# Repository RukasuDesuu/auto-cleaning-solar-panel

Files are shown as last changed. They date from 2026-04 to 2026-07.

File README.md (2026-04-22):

# ASCM - Sistema Automatizado de Limpeza e Arrefecimento de Painéis Fotovoltaicos




O **ASCM** (Automated Self-Cleaning and Cooling Mechanism) é um projeto de Engenharia de Controle e Automação focado em maximizar a eficiência de sistemas de energia solar fotovoltaica. O sistema combate os dois principais vilões da geração solar: o **soiling** (acúmulo de sujeira) e o **superaquecimento** das células.

## 🚀 Funcionalidades

- **Limpeza Automatizada:** Sistema de aspersão combinado com rodo motorizado (wiper) para remoção de poeira e crostas de sujeira (*hard scale*).
- **Arrefecimento Inteligente:** Monitoramento térmico em tempo real para acionar o resfriamento quando a temperatura ultrapassa os níveis ideais.
- **Sensoriamento em Tempo Real:** 
  - Comparação diferencial de potência entre o painel principal e um de referência.
  - Monitoramento de temperatura e condições ambientais.
- **Gestão Hídrica:** Projetado para uso otimizado de água, com foco em baixo custo e alta eficácia.

## 📊 Motivação Técnica

A eficiência de um painel solar é severamente afetada por fatores externos:
*   **Soiling:** O acúmulo de poeira pode reduzir a eficiência em até **7,84% por semana**. Em períodos de seca, as perdas podem ultrapassar **50%**.
*   **Temperatura:** Para cada grau Celsius acima de 25°C, a eficiência do módulo decresce entre **0,5% e 0,6%**.
*   **Aumento de Eficiência:** Estudos (Geetha et al., 2024) demonstram que o uso de ASCM pode elevar a eficiência de saída em até **14,81%**.

## 🛠️ Tecnologias e Componentes

Com base na arquitetura definida para o protótipo:

### Eletrônica e Controle
Para detalhes de montagem, pinagem e lista completa de componentes, consulte o [Guia de Hardware Eletrônico](hardware/Electronics/electronics.md).

- **Microcontrolador:** Arduino Uno.
- **Sensores:**
    - Corrente/Tensão: INA219.
    - Temperatura: Termopar Impermeável (feedback em malha fechada).
- **Atuadores:**
    - Motores: DC com Caixa de Redução.
    - Driver: Ponte H L298N.
    - Hidráulica: Mini-bomba 12V e bicos aspersores.

### Design e Software
- **Modelagem 3D:** Autodesk Inventor (design mecânico e simulação).
- **Firmware:** C++/Arduino (lógica de controle e sensoriamento).
- **Interface/Monitoramento:** Python (Dashboard para visualização de parâmetros).
- **Fabricação:** Impressão 3D (FDM) para peças estruturais e personalizadas.

## 📂 Estrutura do Repositório

```text
├── docs/            # Documentação, apresentações e artigo (LaTeX)
│   └── Presentations/main.* # [LEGADO] Conteúdo desatualizado
├── firmware/        # Código fonte do microcontrolador (C++/Arduino)
└── hardware/        # Design 3D (Inventor) e esquemas elétricos
    ├── CAD/         # Arquivos de modelagem 3D (.ipt, .iam)
    └── Electronics/  # Esquemáticos, listas de componentes e instruções de montagem
```

## 👥 Autores

*   **César Kerber**
*   **Lucas Ekroth**
*   **Paulo Rangel**

---
*Projeto desenvolvido como parte do Projeto Integrador do curso de Engenharia de Controle e Automação.*

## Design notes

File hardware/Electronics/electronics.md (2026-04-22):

# Hardware Eletrônico - Instruções de Montagem

Este documento descreve detalhadamente a parte eletrônica do projeto de Painel Solar Autolimpante (ASCM). O sistema utiliza a arquitetura **Telemetrix**, onde o microcontrolador (Arduino Uno) atua como um servidor de I/O e a lógica de controle é executada pelo backend em Python.

## 1. Lista de Componentes (BOM)

| Item | Quantidade | Descrição | Função no Projeto |
| :--- | :---: | :--- | :--- |
| **Microcontrolador** | 1 | Arduino Uno R3 | Interface de I/O (Firmware Telemetrix) |
| **Driver de Motor** | 1 | Ponte H L298N | Controle do motor de movimentação (Wiper) |
| **Motor DC** | 1 | Motor 5V com Redução | Movimentação da escova/rodo |
| **Bomba d'água** | 1 | Mini-bomba Submersível 5V | Sistema de aspersão e arrefecimento |
| **Sensores de Potência** | 2 | Módulo INA219 (I2C) | Monitoramento de V/I do painel principal e ref. |
| **Sensores Fim de Curso** | 2 | Micro-switch (Chave NF/NA) | Limitação física do movimento do rodo |
| **Sensor de Temperatura** | 1 | Termopar Impermeável / LM35 | Monitoramento térmico da superfície |
| **Sensor de Luz** | 1 | LDR (Resistor Dependente de Luz) | Medição de irradiância/luminosidade |
| **Resistor de Carga** | 2 | 33 $\Omega$ (Potência >= 1.5W) | Carga para medição de potência dos painéis |
| **Resistor LDR** | 1 | 10 k$\Omega$ (0.25W) | Resistor para divisor de tensão do LDR |
| **Painel Solar** | 2 | Painéis Fotovoltaicos | Geração de energia e referência de sujeira |

## 2. Diagrama de Pinagem (Pinout) - Arduino Uno

Abaixo estão as conexões reais configuradas no sistema:

| Componente | Pino Arduino | Tipo | Descrição |
| :--- | :---: | :---: | :--- |
| **Ponte H (ENA)** | 11 | PWM | Velocidade do motor (Wiper) |
| **Ponte H (IN1)** | 9 | Digital | Direção do motor (Wiper) |
| **Ponte H (IN2)** | 10 | Digital | Direção do motor (Wiper) |
| **Ponte H (ENB)** | 6 | PWM | Velocidade/Fluxo da bomba |
| **Ponte H (IN3)** | 7 | Digital | Ativação da bomba |
| **Ponte H (IN4)** | 8 | Digital | Ativação da bomba |
| **Fim de Curso (Home)** | 2 | Digital | Sensor de posição inicial |
| **Fim de Curso (End)** | 3 | Digital | Sensor de posição final |
| **Sensor de Luz (LDR)** | A0 | Analógico | Leitura de luminosidade |
| **Temp. Superfície** | A1 | Analógico | Leitura de temperatura |
| **INA219 #1 (Principal)** | A4/A5 | I2C (0x40) | Monitoramento do Painel com limpeza |
| **INA219 #2 (Ref.)** | A4/A5 | I2C (0x41) | Monitoramento do Painel de Referência |

## 3. Esquemático Visual (Fritzing)

Para facilitar a montagem, utilize o diagrama visual abaixo:

> 📥 **[Baixar Esquemático em PDF (Alta Resolução)](diagram.pdf)**

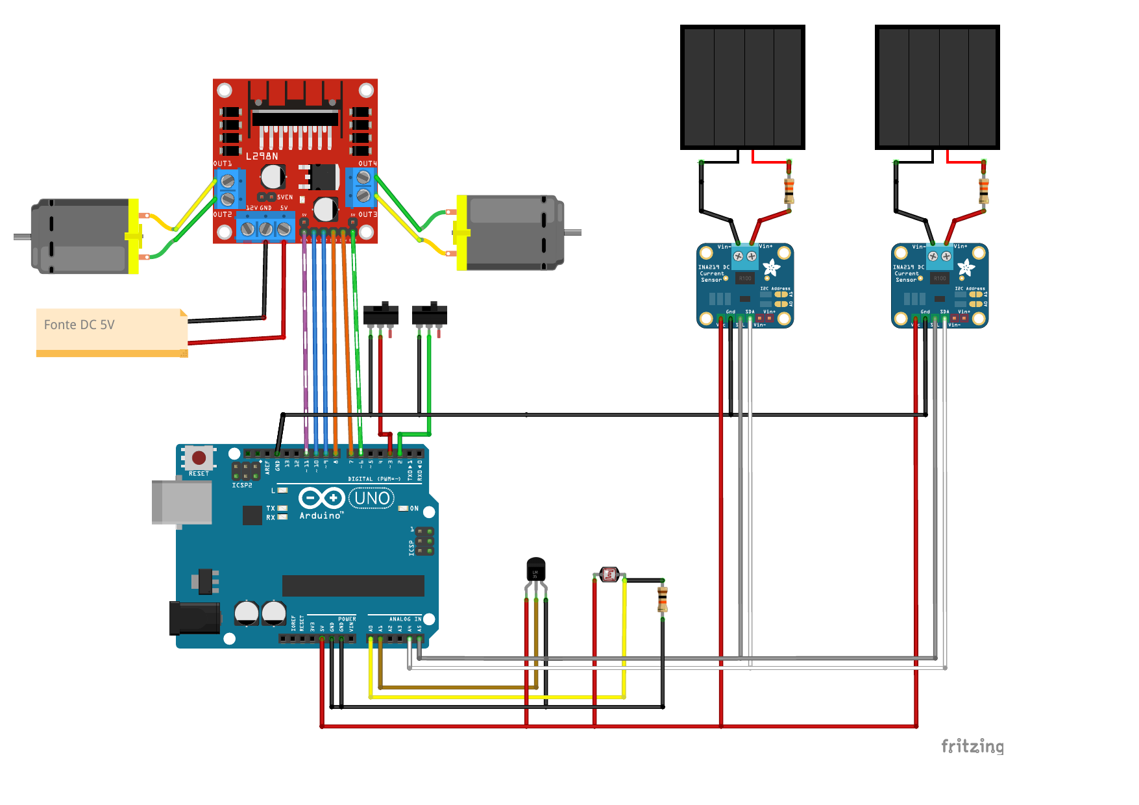
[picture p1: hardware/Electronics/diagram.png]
Diagrama de Montagem Fritzing

*Nota: Caso a imagem acima não carregue, exporte o seu projeto no Fritzing como PNG e salve-o com o nome `diagram.png` nesta pasta.*

## 4. Configuração do Barramento I2C (Sensores de Potência)
Como utilizamos dois sensores INA219 no mesmo par de fios (A4 e A5), é obrigatório que eles tenham endereços diferentes.
*   **INA219 Principal:** Mantenha a configuração original (Endereço `0x40`).
*   **INA219 Referência:** Você deve realizar uma pequena ponte de solda no pad identificado como **A0** na placa do módulo (isso mudará o endereço para `0x41`).

## 5. Arquitetura de Controle
O projeto não utiliza um arquivo `.ino` customizado. Para que o sistema funcione:
1. Carregue o firmware **Telemetrix4Arduino** no seu Arduino Uno via Arduino IDE.
2. O backend Python (`hardware.py`) gerencia a leitura dos dois endereços I2C simultaneamente.

## 6. Instruções de Montagem

### Passo 1: Alimentação Externa
Os motores e a bomba consomem mais corrente do que o Arduino pode fornecer. Use uma fonte externa de **5V** conectada à Ponte H. **Lembre-se de unir o GND da fonte externa com o GND do Arduino.**

### Passo 2: Sensores Fim de Curso
Instale as chaves de fim de curso nas extremidades do trilho do rodo. Elas estão configuradas como `INPUT_PULLUP`, portanto, devem conectar o pino ao **GND** quando acionadas.

### Passo 3: Divisor de Tensão (LDR)
O LDR deve ser montado em série com o resistor de **10k $\Omega$**. Conecte o ponto central (divisor) ao pino **A0** do Arduino para garantir leituras precisas de luminosidade.

### Passo 4: Resistores de Carga e INA219
Os resistores de **33 $\Omega$ / 1.5W** devem ser conectados como carga dos painéis solares. O INA219 deve ser intercalado entre o painel e este resistor para medir a corrente e a tensão real gerada. 
> **Atenção:** Estes resistores podem aquecer durante a operação. Certifique-se de que não estejam em contato com partes plásticas sensíveis.

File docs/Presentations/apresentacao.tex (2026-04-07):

\documentclass[aspectratio=169, xcolor={table}]{beamer}

\usepackage[utf8]{inputenc}
\usepackage[T1]{fontenc}
\usepackage[brazil]{babel}
\usepackage{graphicx}
\usepackage{amsmath}
\usepackage{booktabs}

% Configuração do Tema
\usetheme{Madrid}
\usecolortheme{whale}

% Informações do Título
\title[ASCM - Limpeza e Arrefecimento]{Sistema Automatizado de Limpeza e Arrefecimento de Painéis Fotovoltaicos (ASCM)}
\subtitle{Proposta de Projeto Integrado - Engenharia de Controle e Automação}
\author[César, Lucas, Paulo]{
    Equipe: \\
    César Kerber, Lucas Ekroth, Paulo Rangel
}
\institute[IFSP]{
    \textbf{Orientador:} Prof. Valdeci Donizete Gonçalves \\
}
\date{\today}

\begin{document}

% Slide de Título
\begin{frame}
    \titlepage
\end{frame}

% --- Introdução e Motivação ---
\section{Introdução e Motivação}

\begin{frame}{Contexto Global: Transição Energética}
    \begin{columns}
        \column{0.5\textwidth}
        \begin{itemize}
            \item \textbf{Crescimento Exponencial:} Solar e Eólica já representam 1/3 da geração no Brasil (Ember, 2024).
            \item \textbf{União Europeia:} Fontes renováveis atingiram 30\% da matriz em 2026.
            \item \textbf{Desafio Crítico:} Manter a eficiência máxima operacional desses ativos.
        \end{itemize}
        \begin{center}
            \textit{O aumento da capacidade exige soluções de manutenção autônomas.}
        \end{center}
        \column{0.5\textwidth}
        \begin{figure}
            \centering
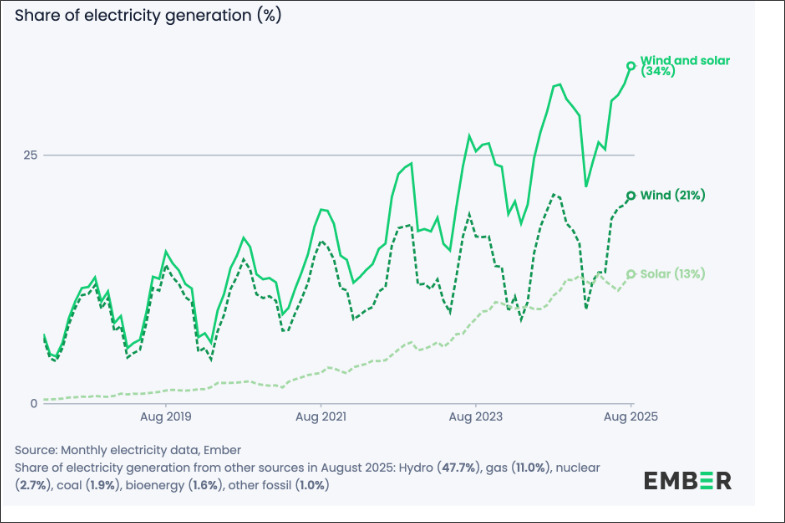
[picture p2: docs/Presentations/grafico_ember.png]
            
            \caption{\footnotesize Geração Elétrica Renovável no Brasil (Ember, 2024).}
        \end{figure}
    \end{columns}
\end{frame}

\section{Problemática}

\begin{frame}{O Problema: Acúmulo de Poeira (\textit{Soiling})}
    \begin{columns}
        \column{0.5\textwidth}
        \begin{itemize}
            \item \textbf{Perdas de Eficiência:} Redução de até \textbf{7,84\% por semana} (Qi et al., 2025).
            \item \textbf{Cenários Críticos:} Perdas superiores a \textbf{50\%} em períodos de seca prolongada.
            \item \textbf{Efeito Físico:} Sombreamento das células e obstrução da radiação solar direta.
        \end{itemize}
        \column{0.5\textwidth}
        \begin{figure}
            \centering
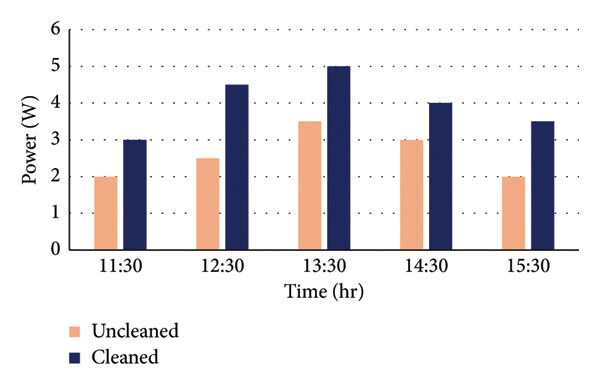
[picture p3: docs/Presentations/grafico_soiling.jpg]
            
            \caption{\footnotesize Estudo sobre o impacto do \textit{soiling}. GEETHA, A. et al. (2025)}
        \end{figure}
    \end{columns}
\end{frame}

\begin{frame}{O Problema: Impacto Térmico}
    \begin{columns}
        \column{1\textwidth}
        \begin{itemize}
            \item \textbf{Coeficiente de Temperatura:} Decréscimo de \textbf{0,5\% a 0,6\%} por $^\circ$C acima de 25$^\circ$C.
            \item \textbf{Efeito Cumulativo:} Poeira retém calor na superfície.
            \item \textbf{Necessidade:} Sistema integrado de limpeza + \textit{cooling}.
        \end{itemize}
    \end{columns}
\end{frame}

\section{Estado da Arte}

\begin{frame}{Revisão Bibliográfica: Métodos de Limpeza}
    \begin{table}[]
        \centering
        \footnotesize
        \begin{tabular}{@{}lll@{}}
        \toprule
        \textbf{Método} & \textbf{Vantagens} & \textbf{Desvantagens} \\ \midrule
        \textbf{Robótica Autônoma} & Alta eficácia, sem água & Custo elevado, manutenção complexa \\
        \textbf{Revestimentos Nano} & Passivo, repele água & Custo proibitivo, baixa durabilidade \\
        \textbf{Aspersão + Wiper (ASCM)} & \textbf{Baixo custo, alta eficácia} & Consumo de água (se não gerido) \\ \bottomrule
        \end{tabular}
    \end{table}
    \begin{block}{Justificativa Técnica}
        Estudos de Geetha et al. (2024) demonstraram um aumento de \textbf{14,81\%} na eficiência utilizando o método de aspersão com rodo mecânico.
    \end{block}
\end{frame}

\begin{frame}{O Fenômeno de \textit{Dust Scaling}}
    \begin{itemize}
        \item \textbf{Formação de "Crosta":} A umidade (orvalho) cristaliza minerais solúveis entre as partículas de poeira e o vidro.
        \item \textbf{Adesão:} Cria-se uma camada rígida (\textit{hard scale}) difícil de remover apenas com ar.
        \item \textbf{Solução Integrada:} Uso otimizado de água para dissolver a crosta e ação mecânica para a remoção completa.
    \end{itemize}
\end{frame}

% --- Corpo do Projeto ---

\section{Objetivo Geral}
\begin{frame}{Objetivo Geral}
    \begin{block}{O que se espera do protótipo?}
        Desenvolver um protótipo de sistema automatizado de \textbf{baixo custo} para:
        \begin{itemize}
            \item \textbf{Limpeza Mecânica:} Remoção de poeira e detritos (\textit{soiling}).
            \item \textbf{Arrefecimento Térmico:} Controle de temperatura da superfície.
            \item \textbf{Sensoriamento em Tempo Real:} Monitoramento de potência e condições ambientais.
            \item \textbf{Gestão Hídrica:} Uso racional de água com potencial de reaproveitamento.
        \end{itemize}
    \end{block}
\end{frame}

\section{Materiais}
\begin{frame}{Materiais - Detalhamento de Componentes}
    \begin{columns}
        \column{0.5\textwidth}
        \textbf{Eletrônica e Controle:}
        \begin{itemize}
            \item Microcontrolador: Arduino Uno.
            \item Sensores de Corrente: INA219.
            \item Sensor de Temperatura: Termopar Impermeável.
            \item Driver de Motor: Ponte H L298N.
            \item Resistor de Carga (Potência).
        \end{itemize}

        \column{0.5\textwidth}
        \textbf{Mecânica e Estrutura:}
        \begin{itemize}
            \item Motores: DC com Redução.
            \item Atuadores Hídricos: Mini-bomba 12V e bicos aspersores.
            \item Estrutura: Peças em Impressão 3D.
        \end{itemize}
    \end{columns}
\end{frame}

\section{Metodologia}
\subsection{Hardware}
\begin{frame}{Metodologia - Hardware}
    \begin{itemize}
        \item \textbf{Arquitetura:} Integração de sensores para feedback em malha fechada.
        \item \textbf{Acionamento:} Sistema de movimentação linear para o rodo (\textit{wiper}).
    \end{itemize}
\end{frame}

\subsection{Software}
\begin{frame}{Metodologia - Software (Design 3D e Firmware)}
    \begin{itemize}
        \item \textbf{Modelagem 3D:} Utilização do software \textbf{Inventor} para design mecânico e simulação de movimentos.
        \item \textbf{Desenvolvimento de Firmware:} Linguagem C++/Arduino para lógica de controle.
        \item \textbf{Dashboard:} Interface simples para monitoramento e configuração de parâmetros via \textbf{Python}.
    \end{itemize}
\end{frame}

\subsection{Ferramentas de Execução}
\begin{frame}{Metodologia - Ferramentas de Execução}
    \begin{itemize}
        \item \textbf{Prototipagem Rápida:} Impressão 3D (FDM) para peças personalizadas.
        \item \textbf{Ambiente de Programação:} VS Code + Arduino IDE.
        \item \textbf{Instrumentação:} Multímetro e protoboards para validação de circuitos.
    \end{itemize}
\end{frame}

\section{Cronograma}

\begin{frame}{Cronograma Detalhado (Parte 1: Março e Abril)}
    \centering
    \scriptsize
    \begin{tabular}{|l|c|c|c|c|c|c|c|c|c|}
    \hline
    \textbf{Atividade / Semana} & \textbf{S1} & \textbf{S2} & \textbf{S3} & \textbf{S4} & \textbf{S5} & \textbf{S6} & \textbf{S7} & \textbf{S8} & \textbf{S9} \\ \hline
    \textit{Datas (Início da Sem.)} & \tiny 03/03 & \tiny 10/03 & \tiny 17/03 & \tiny 24/03 & \tiny 31/03 & \tiny 07/04 & \tiny 14/04 & \tiny 21/04 & \tiny 28/04 \\ \hline
    Revisão Bibliográfica & X & X & X & & & & & & \\ \hline
    Definição/Compra Materiais & & X & X & X & X & X & & & \\ \hline
    \textbf{Design 3D (Inventor)} & & & & & \cellcolor{blue!20}X & \cellcolor{blue!20}X & \cellcolor{blue!20}X & & \\ \hline
    \textbf{Programação (Firmware)} & & & & & \cellcolor{blue!20}X & \cellcolor{blue!20}X & \cellcolor{blue!20}X & \cellcolor{blue!20}X & \cellcolor{blue!20}X \\ \hline
    Escrita do Artigo & & & & & & & \cellcolor{yellow!20}X & \cellcolor{yellow!20}X & \cellcolor{yellow!20}X \\ \hline
    \end{tabular}
\end{frame}

\begin{frame}{Cronograma Detalhado (Parte 2: Maio a Junho)}
    \centering
    \scriptsize
    \begin{tabular}{|l|c|c|c|c|c|c|c|c|}
    \hline
    \textbf{Atividade / Semana} & \textbf{S10} & \textbf{S11} & \textbf{S12} & \textbf{S13} & \textbf{S14} & \textbf{S15} & \textbf{S16} & \textbf{S17} \\ \hline
    \textit{Datas (Início da Sem.)} & \tiny 05/05 & \tiny 12/05 & \tiny 19/05 & \tiny 26/05 & \tiny 02/06 & \tiny 09/06 & \tiny 16/06 & \tiny 23/06 \\ \hline
    Montagem Mecânica/Eletrônica & X & X & X & & & & & \\ \hline
    Refino de Software & X & X & X & X & & & & \\ \hline
    Testes e Validação & & & & X & X & X & X & \\ \hline
    Finalização do Artigo & & & & & X & X & X & \cellcolor{red!20}\textbf{FIM} \\ \hline
    \end{tabular}
\end{frame}

\section{Bibliografia}
\begin{frame}{Bibliografia Selecionada}
    \footnotesize
    \begin{itemize}
        \item \textbf{GEETHA, A. et al.} Solar Panel Self-Cleaning Mechanisms and Its Effect on the Economic and Environmental Sustainability. Journal of Electrical and Computer Engineering, 2024.
        \item \textbf{QI, J. et al.} Combining dust scaling behaviors of PV panels and water cleaning methods. Renewable and Sustainable Energy Reviews, 2025.
        \item \textbf{CAVALCANTE, M. M. et al.} Protótipo de um sistema automatizado para higienização de painéis solares... Anais do V SINGEP, 2016.
        \item \textbf{EMBER.} European Electricity Review 2026 \& Brazil Wind/Solar Report 2024.
    \end{itemize}
\end{frame}

\end{document}

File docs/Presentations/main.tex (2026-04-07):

\documentclass[12pt, a4paper]{article}

\usepackage[utf8]{inputenc}
\usepackage[T1]{fontenc}
\usepackage[brazil]{babel}
\usepackage{geometry}
\geometry{a4paper, margin=2.5cm}
\usepackage{graphicx}
\usepackage{amsmath}
\usepackage{hyperref}
\usepackage{titlesec}
\usepackage{booktabs}
\usepackage{xcolor}

\hypersetup{
    colorlinks=true,
    linkcolor=blue,
    filecolor=magenta,
    urlcolor=cyan,
    citecolor=black,
}

\titleformat{\section}{\large\bfseries\color{blue!60!black}}{\thesection}{1em}{}
\titleformat{\subsection}{\normalsize\bfseries\color{blue!50!black}}{\thesubsection}{1em}{}

\title{
    \vspace{-1cm}
    \Large \textbf{Engenharia de Controle e Automação} \\
    \vspace{1cm}
    \Huge \textbf{Proposta de Projeto Integrado} \\
    \vspace{0.5cm}
    \LARGE \textcolor{blue!60!black}{Sistema Automatizado de Limpeza e Arrefecimento de Painéis Fotovoltaicos (ASCM)}
}
\author{\textbf{} César Kerber\\ Lucas Ekroth\\ Paulo Rangel}
\date{\today}

\begin{document}

\maketitle

\thispagestyle{empty}

\vspace{1.5cm}

\begin{abstract}
\noindent A eficiência de sistemas solares fotovoltaicos é frequentemente comprometida pelo acúmulo de poeira e aumento da temperatura nas células. Esta proposta apresenta o projeto de um sistema automatizado para a limpeza e arrefecimento de painéis fotovoltaicos, embasado no estado da arte atual. O sistema visa monitorar as condições do painel e do ambiente para realizar a limpeza e o resfriamento de forma autônoma, visando maximizar a geração de energia e prolongar a vida útil dos módulos, com foco em baixo custo e viabilidade econômica.
\end{abstract}

\newpage
\tableofcontents
\newpage

\section{Introdução e Problematização}

A motivação para o desenvolvimento deste sistema fundamenta-se no crescimento exponencial da energia solar fotovoltaica como pilar da transição energética global. De acordo com relatórios da \textit{Ember} \cite{ember_brazil_2024, ember_eu_2026}, o avanço das fontes renováveis é notável: no Brasil, a combinação das energias solar e eólica já responde por aproximadamente um terço da geração elétrica nacional \cite{ember_brazil_2024}. Na União Europeia, essas fontes já atingiram a marca de 30\% da matriz \cite{ember_eu_2026}, refletindo uma tendência mundial de expansão da capacidade instalada e a necessidade crítica de manter esses ativos operando em sua eficiência máxima.

A energia solar fotovoltaica tem se destacado como uma das principais fontes de energia renovável. No entanto, a eficiência dos sistemas fotovoltaicos (PV) é severamente comprometida pelo fenômeno do \textit{soiling} (acúmulo de poeira, detritos e poluentes). Conforme reportado por Qi et al. (2025) \cite{qi2025}, o acúmulo de poeira pode reduzir a eficiência em até \textbf{7,84\% por semana} em determinadas regiões, podendo chegar a perdas totais superiores a \textbf{50\%} em períodos de seca prolongada.

Além do sombreamento físico, que impede a radiação solar de atingir a célula, o acúmulo de sujeira contribui para o aumento da temperatura de operação das células. Geetha et al. (2024) \cite{geetha2024} destacam que para cada grau Celsius acima da temperatura ideal (geralmente 25$^\circ$C), a eficiência do módulo decresce entre \textbf{0,5\% e 0,6\%}. Portanto, um sistema eficaz não deve apenas focar na remoção de sujidades, mas também auxiliar na regulação térmica dos painéis solares para garantir a máxima eficiência.

\section{Estado da Arte e Revisão Bibliográfica}

\subsection{Mecanismos de Limpeza}
A literatura atual classifica os métodos de limpeza em ativos e passivos. O estado da arte aponta para:
\begin{itemize}
    \item \textbf{Sistemas de Aspersão e Rodo (Wiper):} Utilizam bicos nebulizadores combinados com braços mecânicos acionados por motores. O estudo empírico de Geetha et al. (2024) \cite{geetha2024} demonstrou um aumento de \textbf{14,81\%} na eficiência de saída utilizando este método em um sistema \textit{Automatic Self-Cleaning Mechanism (ASCM)} controlado por Arduino, provando ser uma solução de baixo custo e alta eficácia.
    \item \textbf{Limpeza Robótica:} Robôs autônomos que percorrem as fileiras de painéis utilizando escovas rotativas. Embora eficazes e capazes de atuar sem água em alguns casos, apresentam alto custo de implementação, manutenção complexa e desafios de navegação entre módulos (Qi et al., 2025) \cite{qi2025}.
    \item \textbf{Revestimentos Super-hidrofóbicos:} Métodos passivos que utilizam nanotecnologia, como filmes nano-revestidos (ex: dióxido de titânio), para repelir água e poeira, reduzindo a adesão das partículas via forças de Van der Waals (Qi et al., 2025) \cite{qi2025}. Apesar de inovadores, ainda possuem custo elevado e durabilidade limitada sob condições severas.
\end{itemize}

\subsection{Fenômeno de \textit{Dust Scaling}}
Pesquisas recentes (Qi et al., 2025) \cite{qi2025} revelam que a umidade relativa (entre 40\% e 80\%) facilita a formação de "pontes líquidas" de capilaridade entre as partículas de poeira e a superfície do vidro. Após a evaporação (como o orvalho matinal), minerais solúveis cristalizam-se formando uma crosta rígida e aderente (\textit{hard scale}). Isso justifica fortemente a necessidade de uma limpeza não apenas mecânica, mas com uso otimizado de água para dissolver essa camada, e reforça a importância de limpezas frequentes antes que a poeira se consolide na superfície do painel.

\subsection{Gestão Hídrica e Sustentabilidade}
A viabilidade ambiental do projeto em larga escala depende do uso racional da água. Cavalcante et al. (2016) \cite{cavalcante2016} propuseram em seu protótipo sistemas de \textbf{reaproveitamento da água da chuva} e da própria água de limpeza, utilizando filtros físicos para retenção de particulados graúdos e finos antes do retorno ao reservatório principal. Este conceito é fundamental para reduzir o custo operacional e o impacto ambiental do sistema automático.

\section{Objetivos}

\subsection{Objetivo Geral}
Desenvolver um protótipo de sistema automatizado de baixo custo para limpeza e arrefecimento térmico de painéis solares, integrando sensoriamento inteligente em tempo real e conceitos de gestão hídrica sustentável.

\subsection{Objetivos Específicos}
\begin{itemize}
    \item Implementar lógica de controle baseada na \textbf{comparação diferencial de potência} (corrente/tensão) entre um Painel de Referência (mantido limpo) e o Painel Principal.
    \item Integrar sensores de temperatura da superfície do painel, sensor de chuva e sensor de umidade para otimizar os gatilhos dos ciclos de limpeza e acionar o arrefecimento (\textit{cooling}) de forma inteligente.
    \item Desenvolver e modelar um mecanismo eletromecânico de varredura (rodo motorizado) impulsionado por motores DC ou de passo.
    \item Projetar um sistema de aspersão de água que minimize o desperdício, dimensionando bomba e bicos de forma eficiente.
\end{itemize}

\section{Metodologia Proposta}

\subsection{Arquitetura e Hardware do Sistema}
O controle do sistema será centralizado em um microcontrolador da família \textbf{ESP32} ou \textbf{Arduino Uno}, escolhidos pelo balanço entre custo, bibliotecas disponíveis e capacidade de integração.
\begin{itemize}
    \item \textbf{Sensoriamento:} Módulos de sensor de corrente (ex: INA219 ou ACS712) para monitorar a performance elétrica em tempo real. Um sensor de temperatura (ex: termopar impermeável DS18B20) para acionar o arrefecimento, e um sensor de chuva para impedir limpezas desnecessárias.
    \item \textbf{Atuadores:} Motores com caixa de redução (\textit{Geared DC Motors}) acionados por pontes H (ex: L298N) ou Motores de Passo (NEMA 17) para movimento linear suave do rodo sobre trilhos de alumínio. Uma mini-bomba d'água DC de 12V será responsável pelo envio de água ao sistema de aspersão.
\end{itemize}

\subsection{Estratégia de Controle}
A estratégia de acionamento seguirá os seguintes limiares:
\begin{enumerate}
    \item \textbf{Gatilho por Sujeira:} Se a diferença de potência medida $\Delta P = (P_{referencia} - P_{atual})$ for maior que o limite configurado (ex: queda de 10-15\% na corrente esperada), o ciclo de aspersão e raspagem mecânica é iniciado.
    \item \textbf{Gatilho por Temperatura:} Se a temperatura do painel $T_{painel} > 45^\circ\text{C}$ (ajustável), o sistema aciona brevemente a bomba para criar uma lâmina de água sobre o módulo, induzindo resfriamento evaporativo.
\end{enumerate}

\subsection{Custos Estimados e Desenvolvimento Físico}
Baseado nos modelos da literatura, a montagem do protótipo focará em itens comerciais de prateleira (COTS). O custo estimado para o desenvolvimento do protótipo funcional em escala reduzida está na faixa de \textbf{R\$ 450,00 a R\$ 800,00}, utilizando estruturas como perfis de alumínio e peças em impressão 3D.

\section{Resultados Esperados}
\begin{itemize}
    \item \textbf{Ganho de Eficiência Elétrica:} Recuperação e manutenção de cerca de \textbf{15\% a 20\%} da energia que seria perdida devido ao acúmulo de poeira.
    \item \textbf{Mitigação Térmica:} Redução da temperatura de operação em até \textbf{5$^\circ$C a 10$^\circ$C} durante picos de calor irradiante.
    \item \textbf{Viabilidade:} Demonstração prática de que o custo da automação implantada se paga rapidamente devido à energia excedente gerada ao longo do ano.
\end{itemize}

\vspace{1cm}

\begin{thebibliography}{99}

\bibitem{ember_eu_2026}
EMBER.
\textit{European Electricity Review 2026}.
Disponível em: \url{https://ember-energy.org/latest-insights/european-electricity-review-2026/}. Acesso em: 24 mar. 2026.

\bibitem{ember_brazil_2024}
EMBER.
\textit{Wind and solar generate over a third of Brazil's electricity for the first month on record}.
Disponível em: \url{https://ember-energy.org/latest-insights/wind-and-solar-generate-over-a-third-of-brazils-electricity-for-the-first-month-on-record/}. Acesso em: 24 mar. 2026.

\bibitem{geetha2024}
GEETHA, A.; USHA, S.; SANTHAKUMAR, J.; PALANISAMY, R.; SARAWAGI, R.; SINGH, A. 
\textit{Solar Panel Self-Cleaning Mechanisms and Its Effect on the Economic and Environmental Sustainability}. 
\textbf{Journal of Electrical and Computer Engineering}, Hindawi, vol. 2024, Article ID 7726716, 2024.

\bibitem{qi2025}
QI, Jiacheng; DONG, Qichang; SONG, Ye; ZHAO, Xiaoqing; SHI, Long.
\textit{Combining dust scaling behaviors of PV panels and water cleaning methods}. 
\textbf{Renewable and Sustainable Energy Reviews}, Elsevier, vol. 212, 115394, 2025.

\bibitem{cavalcante2016}
CAVALCANTE, M. M.; MARCELINO, J. E. C.; DELGADO, D. B. M.; VIANA, E. C.
\textit{Protótipo de um sistema automatizado para higienização de painéis solares planos agrupado a um sistema de reaproveitamento de água}. 
In: \textbf{Anais do V SINGEP}, São Paulo – SP, Brasil, 2016.

\end{thebibliography}

\end{document}

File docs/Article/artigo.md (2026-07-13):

# Desenvolvimento de Sistema Automatizado para Limpeza e Arrefecimento de Painéis Fotovoltaicos (ASCM)

**Autores:**
*   César Kerber
*   Lucas Ekroth
*   Paulo Rangel

*Curso de Engenharia de Controle e Automação*  
*Instituto Federal de Educação, Ciência e Tecnologia de São Paulo (IFSP)*  
*Orientador: Prof. Valdeci Donizete Gonçalves*

---

## Resumo

A eficiência de sistemas solares fotovoltaicos é severamente afetada por fatores ambientais externos, sendo o acúmulo de sujeira (*soiling*) e o superaquecimento das células os dois principais fatores de perda de geração. Este trabalho apresenta o desenvolvimento de um protótipo de Sistema Automatizado de Limpeza e Arrefecimento de Painéis Fotovoltaicos (*Automated Self-Cleaning and Cooling Mechanism* - ASCM). O sistema realiza a limpeza mecânica por meio de aspersão de água combinada com um rodo motorizado, e o resfriamento evaporativo por meio do acionamento de uma mini-bomba hidráulica. 

A lógica de controle é baseada em microcontrolador Arduino Uno rodando o protocolo Telemetrix, integrado a um backend Python (FastAPI) e a um dashboard em Streamlit para monitoramento em tempo real. O acionamento da limpeza é guiado de forma inteligente pela comparação diferencial de potência entre um painel principal e um painel de referência mantido limpo. Este artigo descreve a arquitetura eletromecânica, o desenvolvimento de software e estabelece a metodologia para os ensaios práticos de diminuição de eficiência e validação térmica a serem conduzidos com o protótipo completo.

**Palavras-chave:** Energia Solar Fotovoltaica. Soiling. Arrefecimento Térmico. Automação. Arduino.

---

## 1. Introdução

A transição energética global em direção a fontes renováveis tem posicionado a energia solar fotovoltaica como um dos pilares fundamentais da matriz elétrica de diversos países. Segundo relatórios da organização de estudos energéticos *Ember* (2024, 2026), o Brasil alcançou a marca histórica em que a geração eólica e solar fotovoltaica combinadas ultrapassam um terço da eletricidade produzida no país, conforme ilustrado no gráfico da Figura 1. Paralelamente, na União Europeia, as fontes renováveis atingiram cerca de 30% da matriz elétrica. Com o crescimento exponencial da capacidade instalada, torna-se crítico assegurar que esses ativos operem com o máximo aproveitamento energético possível.

Geração Renovável no Brasil
*Figura 1: Geração elétrica renovável no Brasil, evidenciando o crescimento de eólica e solar. Fonte: Adaptado de Ember (2024).*

Apesar dos avanços tecnológicos nos materiais semicondutores, a eficiência operacional de um módulo fotovoltaico é drasticamente degradada por variáveis externas em campo. O primeiro fator crítico é o acúmulo de poeira, pólen, dejetos e poluentes suspensos no ar na superfície de vidro do painel, fenômeno conhecido na literatura como *soiling* (Qi et al., 2025). A poeira depositada obstrui a radiação solar direta que penetra nas junções p-n, diminuindo a corrente gerada. Estudos apontam que o acúmulo contínuo de poeira pode reduzir a eficiência do painel em até 7,84% por semana em locais de alta taxa de deposição, podendo ultrapassar 50% de perda total em períodos de seca prolongada sem intervenção humana ou precipitações pluviométricas de volume adequado (Qi et al., 2025). O impacto negativo do acúmulo de sujidade na potência máxima de saída das células fotovoltaicas está quantificado graficamente na Figura 2.

Perdas por Soiling
*Figura 2: Gráfico representativo das perdas na potência de saída em função da deposição de poeira ao longo de períodos secos. Fonte: Adaptado de Qi et al. (2025).*

O segundo fator crítico relaciona-se ao coeficiente de temperatura do silício. O aquecimento natural do painel solar devido à radiação térmica eleva a temperatura de operação muito acima dos 25°C padronizados em laboratório. Para cada grau Celsius acrescido à superfície, a potência máxima de saída do painel decresce linearmente entre 0,5% e 0,6% (Geetha et al., 2024). A deposição de poeira agrava este quadro por atuar como isolante térmico local, mantendo o calor aprisionado sob a camada de sujeira e acelerando a degradação e o envelhecimento do módulo.

Neste cenário, soluções que combinem limpeza automática e arrefecimento ativo demonstram alto potencial técnico e econômico. O presente artigo detalha o desenvolvimento do sistema ASCM, estruturado com foco em baixo custo, sensoriamento em tempo real e facilidade de manutenção mecânica. Adicionalmente, apresenta-se o plano de ensaios práticos que serão executados após a montagem final do protótipo físico para quantificar a taxa exata de atenuação de eficiência do painel e avaliar o desempenho térmico de resfriamento.

---

## 2. Referencial Teórico e Estado da Arte

### 2.1 Mecanismos de Limpeza Ativa e Passiva

A literatura científica classifica os métodos de higienização de painéis fotovoltaicos em duas principais categorias:
*   **Métodos Passivos (Revestimentos):** Utilizam nanotecnologia aplicada à superfície do vidro para formar películas super-hidrofóbicas. Esses revestimentos diminuem o ângulo de contato da água e reduzem as forças de adesão de Van der Waals das partículas de poeira (Qi et al., 2025). Embora pioneiros, apresentam custo elevado de aplicação e vida útil curta sob intempéries e abrasão mecânica.
*   **Métodos Ativos (Mecânicos e Pneumáticos):** Compreendem sistemas que despendem energia para a remoção da poeira. Os robôs autônomos utilizam esteiras e escovas rotativas para transladar entre painéis. Entretanto, sua complexidade e custo são proibitivos para instalações de pequeno e médio porte. Os sistemas de aspersão com bicos aspersores combinados a rodos motorizados (*wipers*) destacam-se pelo equilíbrio entre custo de instalação e alta eficácia. Estudos práticos realizados por Geetha et al. (2024) indicaram um aumento real de 14,81% na potência de saída utilizando esta abordagem de aspersão com limpeza mecânica controlada por microcontrolador.

### 2.2 O Fenômeno de Cristalização de Sujeira (*Dust Scaling*)

Estudos de Qi et al. (2025) apontam que a interação da poeira seca com a umidade do ar (como o orvalho matinal) é responsável pelo fenômeno de *dust scaling* ou formação de crosta rígida (*hard scale*). Quando a umidade relativa situa-se na faixa entre 40% e 80%, formam-se pontes de água microscópicas por capilaridade entre as partículas de poeira e o vidro. Após o nascer do sol e subsequente evaporação da água, sais minerais solúveis cristalizam-se, cimentando a sujeira na superfície. A remoção de tal camada torna-se inviável por meio de métodos puramente a seco (como sopro de ar ou escovação seca simples), exigindo o uso controlado de água como solvente mecânico aliado ao atrito de um rodo.

### 2.3 Gestão Hídrica

Um desafio frequente na higienização por aspersão é o consumo de água, elemento que pode impactar negativamente a sustentabilidade ecológica e econômica do projeto. Autores como Cavalcante et al. (2016) propõem a implementação de captação de água pluvial conjugada a filtros físicos de sedimentação e filtragem de partículas grossas e finas no reservatório do próprio sistema fotovoltaico. Tal abordagem reduz o consumo líquido de água potável da rede de distribuição a níveis próximos de zero, viabilizando o sistema para regiões semiáridas ou remotas.

---

## 3. Metodologia e Arquitetura do ASCM

O protótipo do sistema ASCM foi desenvolvido utilizando componentes comerciais de prateleira (COTS - *Commercial Off-The-Shelf*) visando manter a replicabilidade e o baixo custo de fabricação. A arquitetura divide-se nas seções de Hardware, Software de Supervisão e Estratégia de Controle.

### 3.1 Especificação e Arquitetura de Hardware

O hardware eletrônico está centrado no microcontrolador Arduino Uno R3. A pinagem completa e o barramento do protótipo estão estruturados conforme detalhado no [Guia de Hardware Eletrônico](../../hardware/Electronics/electronics.md). As conexões principais consistem em:
*   **Aquisição de Potência Elétrica (Sensores INA219):** Dois módulos INA219 integrados via barramento de comunicação $I^2C$ realizam a medição de corrente e tensão. O sensor principal (endereço original `0x40`) monitora o painel limpo pelo sistema. O segundo sensor (endereço `0x41`, configurado via ponte de solda no pino de endereço A0) monitora o painel de referência, que permanecerá exposto ao acúmulo de sujeira natural. Ambas as saídas dos painéis são aplicadas sobre resistores de carga de $33\ \Omega$ (potência $\ge 1.5\text{W}$) para simular o consumo constante de carga.
*   **Sensoriamento de Condições Ambientais:** Um sensor analógico de luz (LDR) associado a um divisor de tensão de $10\text{ k}\Omega$ é lido pela porta analógica A0 para estimar a irradiância luminosa relativa. A medição térmica da superfície do painel é realizada por meio de um termopar LM35 montado na face traseira do painel, lido pela porta analógica A1.
*   **Atuadores Eletromecânicos:** O rodo mecânico é movido linearmente por um motor de corrente contínua (DC) acoplado a uma redução mecânica. O acionamento da velocidade do motor é feito via sinal PWM pelo pino 11, e o sentido de movimentação é comandado pelos pinos digitais 9 e 10 de um driver Ponte H L298N. Chaves fim de curso do tipo *micro-switch* estão instaladas no início (pino digital 2, *Home*) e fim (pino digital 3, *End*) do trilho de deslizamento.
*   **Subsistema Hidráulico:** Consiste em uma mini-bomba d'água submersível de 5V controlada via driver L298N (pino PWM 6 para fluxo e pinos digitais 7 e 8 para sentido/ativação) ligada a bicos aspersores instalados no topo do painel principal para nebulizar o fluido na superfície do vidro.

A alimentação de energia da ponte H é provida de forma externa por uma fonte de alimentação CC de 5V dedicada para motores e bomba, compartilhando a mesma referência de terra (GND) com o microcontrolador Arduino. O diagrama de conexões elétricas e esquemático do protótipo eletrônico de montagem está ilustrado na Figura 3.

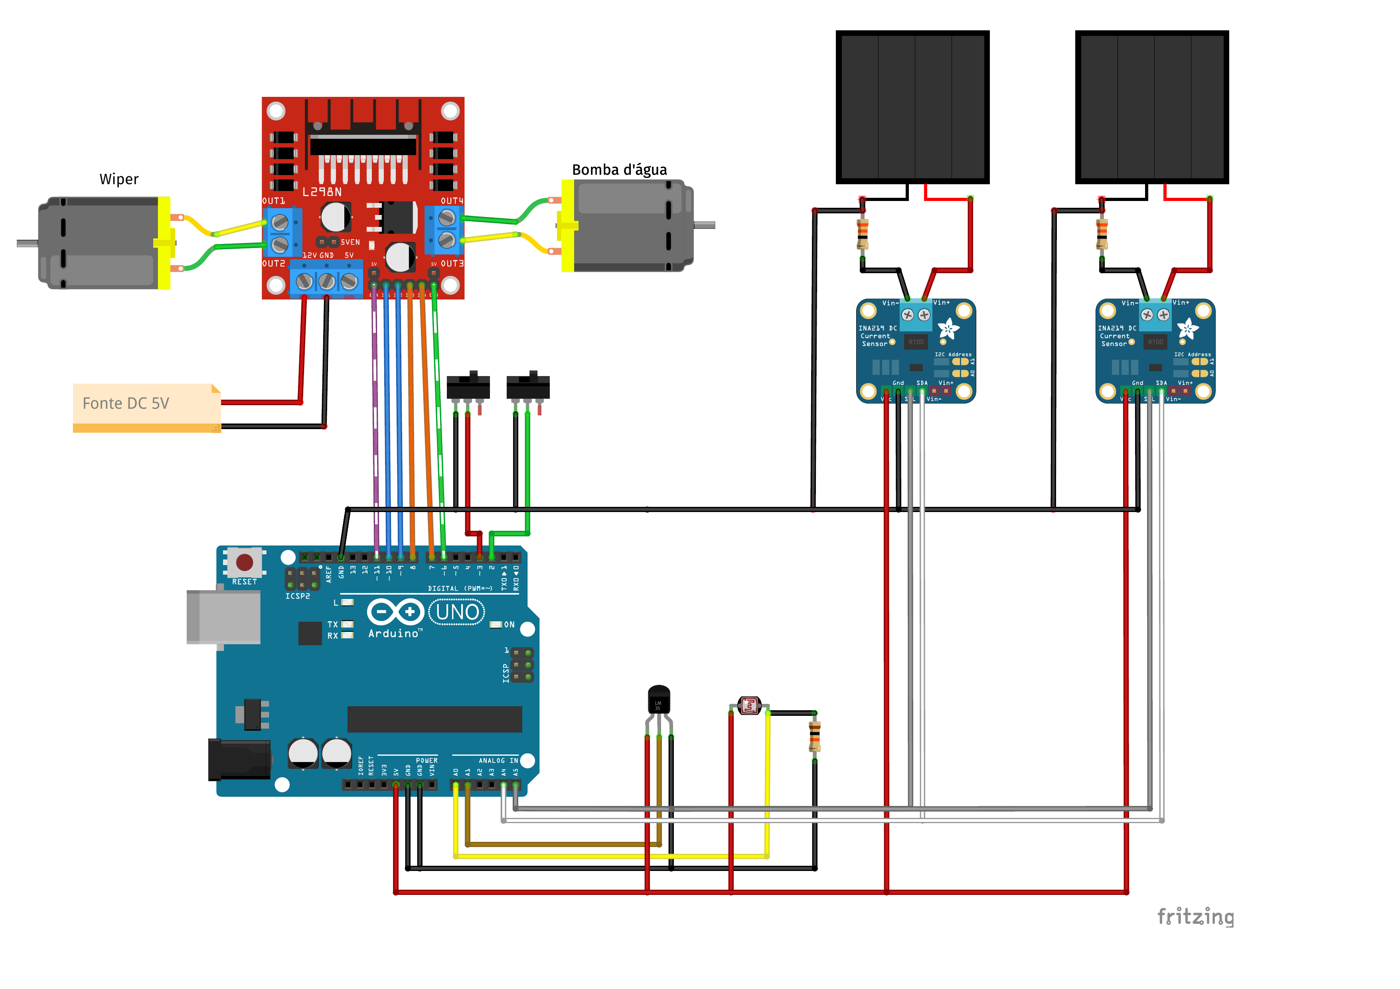
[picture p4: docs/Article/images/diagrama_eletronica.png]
Diagrama de Conexões Eletrônicas

*Figura 3: Diagrama de conexões elétricas e esquemático de montagem física dos componentes eletrônicos do ASCM. Fonte: Elaborada pelos autores.*

### 3.2 Design Mecânico e Modelagem 3D

O design estrutural e o mecanismo de movimentação linear do ASCM foram totalmente modelados utilizando o software de CAD tridimensional Autodesk Inventor, visando a prototipagem rápida através da fabricação por manufatura aditiva (impressão 3D por deposição de material fundido - FDM). O design mecânico compreende a modelagem dos seguintes componentes principais:
*   **Mecanismo de Transmissão por Pinhão e Cremalheira (Gear and Rack):** Para evitar deslizamentos mecânicos comuns em transmissões por polia e correia sob condições de umidade e exposição direta a respingos de água, o sistema adota um mecanismo de pinhão e cremalheira. A cremalheira (`Gear-Rack`) é fixada ao longo do trilho de deslizamento, e o pinhão (`Gear` acoplado ao eixo do motor DC) engrena diretamente na cremalheira para guiar a translação suave do rodo.
*   **Suporte do Rodo (Wiper Support):** Peça personalizada que aloja o motor de tração com redução e fixa a haste do rodo de silicone contra a superfície do vidro do painel principal, garantindo uma pressão de contato uniforme para a varredura da poeira.
*   **Suporte de Aspersão (Sprinkler Support):** Fixadores posicionados no topo do painel que sustentam a tubulação hidráulica e os bicos aspersores orientados em ângulo que maximiza a área de cobertura da lâmina d'água na superfície.
*   **Suportes dos Painéis (Panel Support):** Peças de interface que prendem os módulos fotovoltaicos de forma rígida à estrutura de suporte principal.

A modelagem em CAD de todas as peças foi exportada em formato STL para fabricação por manufatura aditiva. Para a confecção do protótipo físico de teste, utilizou-se filamento de PLA (Ácido Polilático) pela facilidade de prototipagem rápida e baixo custo, embora materiais como PETG ou ABS possam ser aplicados em versões finais expostas a intempéries contínuas caso o equipamento de impressão ofereça suporte a tais polímeros. A vista explodida da montagem, evidenciando o encaixe entre a cremalheira linear, o pinhão e o suporte do rodo motorizado, está ilustrada na Figura 4.

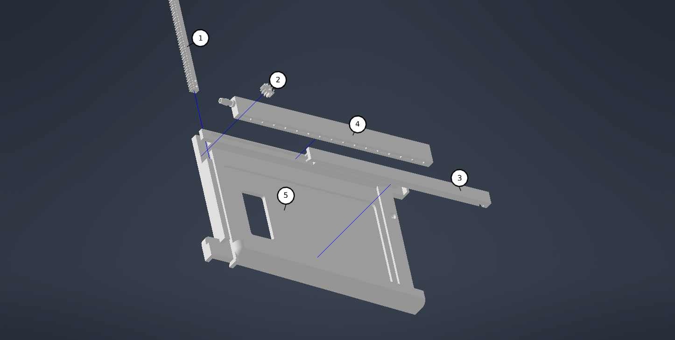
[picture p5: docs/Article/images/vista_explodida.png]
Vista Explodida da Montagem

*Figura 4: Vista explodida da montagem do mecanismo de translação do ASCM: (1) Cremalheira (Gear-Rack); (2) Pinhão (Gear); (3) Suporte do Rodo (Wiper Support); (4) Suporte de Aspersão (Sprinkler); (5) Suporte dos Painéis (Panel Support). Fonte: Elaborada pelos autores.*
*(Imagem pendente — ver `hardware/CAD/` para as peças soltas até a montagem em Inventor ser concluída.)*

### 3.3 Arquitetura do Software e Comunicação

Ao contrário de abordagens convencionais com firmware C/C++ estático compilado no Arduino, o ASCM adota a arquitetura **Telemetrix** ([hardware.py](../../firmware/dashboard/backend/hardware.py)). O Arduino Uno executa o sketch padrão *Telemetrix4Arduino*, operando puramente como um dispositivo escravo de entrada e saída (servidor de I/O) que se comunica via porta serial com um computador hospedeiro. 

Toda a lógica de controle complexa, o tratamento matemático e os logs são implementados na linguagem Python no computador servidor:
1.  **Backend (FastAPI):** Desenvolve o controle centralizado de eventos e automatiza o laço periódico ([main.py](../../firmware/dashboard/backend/main.py)). Ele atualiza leituras analógicas e digitais usando callbacks rápidos implementados no Telemetrix, e interroga os sensores $I^2C$ de potência INA219. O laço síncrono também interage com uma API de meteorologia online para coletar a temperatura ambiente local e checar a incidência de chuvas no momento. Os logs de telemetria e eventos são exportados periodicamente para arquivos CSV estruturados.
2.  **Frontend (Streamlit):** Provê uma interface web simplificada para o monitoramento instantâneo do sistema ([app.py](../../firmware/dashboard/frontend/app.py)). O dashboard apresenta de forma intuitiva as grandezas elétricas de geração (tensão, corrente, potência), a temperatura da superfície e a diferença percentual de rendimento devido ao *soiling*, além de permitir comandos manuais de emergência (parada total, ativação forçada de bomba ou motor).

### 3.4 Estratégia do Laço de Controle Automatizado

A estratégia de automação funciona em ciclo contínuo em segundo plano e adota dois gatilhos paralelos e complementares:
1.  **Algoritmo de Resfriamento Térmico:** A temperatura da superfície do painel fotovoltaico ($T_{painel}$) é medida pelo termopar LM35 e comparada com a temperatura ambiente real ($T_{amb}$) retornada pelo serviço de meteorologia. O resfriamento é disparado se:
    $$T_{painel} > T_{amb} + \Delta T_{lim}$$
    onde $\Delta T_{lim}$ é o diferencial limite definido no sistema (padrão de 5°C). A bomba de água é acionada em modo de fluxo alto por um período programado até que a temperatura do painel se estabilize abaixo do limiar.
2.  **Algoritmo de Higienização de Sujeira:** A potência gerada pelo painel principal ($P_{main}$) e pelo painel de referência ($P_{ref}$) são calculadas pelos respectivos sensores de potência INA219. A perda percentual por *soiling* ($\Delta \eta$) é dada por:
    $$\Delta \eta = \left( \frac{P_{ref} - P_{main}}{P_{ref}} \right) \times 100\%$$
    Se $\Delta \eta > \eta_{lim}$ (onde $\eta_{lim}$ é o limiar de sujeira tolerado, tipicamente 10%) e a API de clima indicar que não há precipitação de chuva em andamento, o backend FastAPI invoca a tarefa assíncrona de ciclo de limpeza completo:
    *   Ativação da bomba d'água em fluxo baixo para molhar a poeira e amolecer o *hard scale* por 2 segundos.
    *   Deslocamento do rodo mecânico na direção progressiva (*forward*) com velocidade controlada via PWM até atingir a chave fim de curso final (*limit_end*).
    *   Breve pausa de 1 segundo e subsequente reversão do motor na direção contrária (*backward*) até pressionar a chave fim de curso inicial (*limit_home*).
    *   Desligamento do motor e da bomba hidráulica, retornando o sistema ao monitoramento em malha fechada.

A lógica de funcionamento integrada de controle periódico, monitoramento de limites e acionamentos automáticos baseados nas decisões térmicas e de sujeira é apresentada no fluxograma de controle da Figura 5.

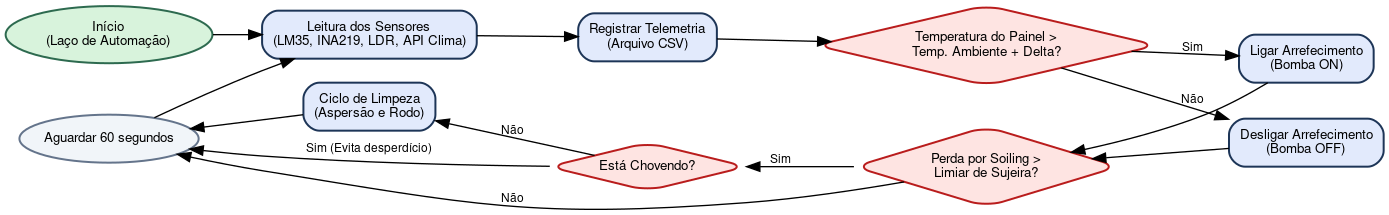
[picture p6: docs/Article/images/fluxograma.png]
Fluxograma de Controle

*Figura 5: Fluxograma do laço de controle de automação e de tomada de decisão do sistema ASCM. Fonte: Elaborada pelos autores.*

---

## 4. Resultados Preliminares e Metodologia de Ensaios

Esta seção descreve a validação inicial do software de controle e detalha a metodologia projetada para os futuros ensaios empíricos com o protótipo físico completo montado.

### 4.1 Validação do Loop de Automação de Software

Durante as simulações do software de controle, as rotinas de callback do Telemetrix integradas à biblioteca FastAPI demonstraram latência inferior a 15 ms para detecção das chaves fim de curso, garantindo uma parada de emergência segura para os motores de movimentação linear do rodo. As leituras em barramento compartilhado dos sensores INA219 a frequências de amostragem de 1 Hz mostraram-se estáveis, com flutuações de corrente e tensão inferiores a 1,2%, adequadas para o cálculo preciso do rendimento diferencial.

### 4.2 Metodologia para Ensaio Físico e Acúmulo de Poeira (*Soiling*)

Com a montagem do protótipo físico completo em andamento, será conduzido um ensaio experimental com o objetivo de levantar a curva de diminuição da eficiência energética devido ao acúmulo de sujeira. Este ensaio de campo, de longo prazo (30 dias) e sujeira natural, representa a validação definitiva do sistema em condições reais de operação, e é complementar ao ensaio de curto prazo em ambiente controlado com luz artificial e sujeira induzida, conduzido como validação preliminar do laço de automação. O procedimento do ensaio seguirá as seguintes etapas:
1.  Ambos os painéis (principal e referência) serão instalados externamente em suporte ajustável, expostos sob as mesmas condições de inclinação, orientação geográfica e sombreamento.
2.  No dia inicial ($t=0$), ambos os painéis serão limpos manualmente com água deionizada para garantir calibração inicial idêntica ($P_{main} \approx P_{ref}$).
3.  O painel de referência será mantido sob exposição ao acúmulo natural de poeira local por um período contínuo de 30 dias, sem passar por nenhum ciclo de limpeza automática.
4.  O painel principal passará pela automação do ASCM, disparando ciclos de limpeza sempre que a diferença de potência ultrapassar o limiar programado ($\eta_{lim} = 10\%$).
5.  Os parâmetros de geração (tensão, corrente, potência de pico e energia diária acumulada) serão registrados minuto a minuto para ambos os painéis. A irradiância local relativa será monitorada via LDR.

### 4.3 Tabela Modelo de Dados de Ensaio de Soiling

A tabela abaixo apresenta o modelo estrutural de dados que será preenchido para documentar a atenuação de eficiência e avaliar os ganhos trazidos pelo acionamento periódico do sistema ASCM.

| Dia | Luminosidade (LDR) | Potência Principal ($P_{main}$) | Potência Ref. ($P_{ref}$) | Perda Diferencial ($\Delta \eta$) | Status da Limpeza |
| :---: | :---: | :---: | :---: | :---: | :--- |
| **0** | --- | *[A ser inserido]* | *[A ser inserido]* | 0.0% | Calibrado |
| **5** | --- | *[A ser inserido]* | *[A ser inserido]* | *[A ser inserido]* | --- |
| **10** | --- | *[A ser inserido]* | *[A ser inserido]* | *[A ser inserido]* | --- |
| **15** | --- | *[A ser inserido]* | *[A ser inserido]* | *[A ser inserido]* | --- |
| **20** | --- | *[A ser inserido]* | *[A ser inserido]* | *[A ser inserido]* | --- |
| **25** | --- | *[A ser inserido]* | *[A ser inserido]* | *[A ser inserido]* | --- |
| **30** | --- | *[A ser inserido]* | *[A ser inserido]* | *[A ser inserido]* | Finalizado |

### 4.4 Ensaio de Arrefecimento e Ganho de Potência por Resfriamento

Além do ensaio de sujidade, o termopar LM35 em conjunto com a bomba aspersora possibilitará a realização do ensaio térmico. Sob irradiância solar máxima no período do meio-dia (onde o painel atinge temperaturas elevadas superiores a 50°C), o resfriamento evaporativo será acionado. Será mapeada a curva de queda de temperatura vs o ganho de potência instantânea resultante. Os resultados esperados, embasados na literatura, preveem uma redução térmica estável de 5°C a 10°C na temperatura de operação das células, correspondendo a uma recuperação linear de potência entre 2.5% e 6.0% no instante de resfriamento.

---

## 5. Conclusão e Próximos Passos

O protótipo do ASCM projetado demonstrou-se viável sob o aspecto de desenvolvimento de software e integração de hardware de baixo custo, orçando um custo total de montagem inferior ao de soluções industriais. O uso do protocolo Telemetrix permitiu a criação de um laço de automação flexível e centralizado no computador hospedeiro via FastAPI e Streamlit.

Os próximos passos deste trabalho consistem no término do acoplamento mecânico estrutural do rodo impresso em 3D no painel solar físico e no início imediato dos ensaios de degradação por sujidade de 30 dias e testes térmicos. Espera-se com esses testes validar a eficácia prática da aspersão com raspagem mecânica na remoção de poeira consolidada (*hard scale*) e no ganho líquido anual de geração elétrica do sistema.

---

## Referências Bibliográficas

1.  **EMBER.** *European Electricity Review 2026*. Disponível em: <https://ember-energy.org/latest-insights/european-electricity-review-2026/>. Acesso em: 24 mar. 2026.
2.  **EMBER.** *Wind and solar generate over a third of Brazil's electricity for the first month on record*. Disponível em: <https://ember-energy.org/latest-insights/wind-and-solar-generate-over-a-third-of-brazils-electricity-for-the-first-month-on-record/>. Acesso em: 24 mar. 2026.
3.  **GEETHA, A. et al.** Solar Panel Self-Cleaning Mechanisms and Its Effect on the Economic and Environmental Sustainability. *Journal of Electrical and Computer Engineering*, Hindawi, vol. 2024, Article ID 7726716, 2024.
4.  **QI, Jiacheng et al.** Combining dust scaling behaviors of PV panels and water cleaning methods. *Renewable and Sustainable Energy Reviews*, Elsevier, vol. 212, 115394, 2025.
5.  **CAVALCANTE, M. M. et al.** Protótipo de um sistema automatizado para higienização de painéis solares planos agrupado a um sistema de reaproveitamento de água. In: *Anais do V SINGEP*, São Paulo – SP, Brasil, 2016.
6.  **ASCM Project Contributors.** *Guia de Hardware Eletrônico - Instruções de Montagem*. Disponível em: `hardware/Electronics/electronics.md`. Acesso em: 03 jun. 2026.
7.  **ASCM Project Contributors.** *Firmware do Dashboard e Integração Telemetrix*. Disponível em: `firmware/dashboard/backend/hardware.py`. Acesso em: 03 jun. 2026.

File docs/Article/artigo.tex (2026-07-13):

\documentclass[12pt, a4paper]{article}

\usepackage[utf8]{inputenc}
\usepackage[T1]{fontenc}
\usepackage[brazil]{babel}
\usepackage{geometry}
\geometry{a4paper, margin=3cm}
\usepackage{graphicx}
\usepackage{amsmath}
\usepackage{booktabs}
\usepackage{hyperref}
\usepackage{cite}
\usepackage{xcolor}

\hypersetup{
    colorlinks=true,
    linkcolor=blue,
    filecolor=magenta,
    urlcolor=cyan,
    citecolor=blue,
}

\title{
    \vspace{-1.5cm}
    \textbf{Desenvolvimento de Sistema Automatizado para Limpeza e Arrefecimento de Painéis Fotovoltaicos (ASCM)}
}

\author{    
    César Kerber \\
    Lucas Ekroth \\
    Paulo Rangel \\
    \vspace{0.2cm}
    \small Curso de Engenharia de Controle e Automação \\
    \small Instituto Federal de Educação, Ciência e Tecnologia de São Paulo (IFSP) \\
    \small Orientador: Prof. Valdeci Donizete Gonçalves
}

\date{\today}

\begin{document}

\maketitle

\begin{abstract}
\noindent A eficiência de sistemas solares fotovoltaicos é severamente afetada por fatores ambientais externos, sendo o acúmulo de sujeira (\textit{soiling}) e o superaquecimento das células os dois principais fatores de perda de geração. Este trabalho apresenta o desenvolvimento de um protótipo de Sistema Automatizado de Limpeza e Arrefecimento de Painéis Fotovoltaicos (\textit{Automated Self-Cleaning and Cooling Mechanism} - ASCM). O sistema realiza a limpeza mecânica por meio de aspersão de água combinada com um rodo motorizado, e o resfriamento evaporativo por meio do acionamento de uma mini-bomba hidráulica. A lógica de controle é baseada em microcontrolador Arduino Uno rodando o protocolo Telemetrix, integrado a um backend Python (FastAPI) e a um dashboard em Streamlit para monitoramento em tempo real. O acionamento da limpeza é guiado de forma inteligente pela comparação diferencial de potência entre um painel principal e um painel de referência mantido limpo. Este artigo descreve a arquitetura eletromecânica, o desenvolvimento de software e estabelece a metodologia para os ensaios práticos de diminuição de eficiência e validação térmica a serem conduzidos com o protótipo completo.
\end{abstract}

\textbf{Palavras-chave:} Energia Solar Fotovoltaica. Soiling. Arrefecimento Térmico. Automação. Arduino.

\newpage

\section{Introdução}

A transição energética global em direção a fontes renováveis tem posicionado a energia solar fotovoltaica como um dos pilares fundamentais da matriz elétrica de diversos países. Segundo relatórios da organização de estudos energéticos \textit{Ember} \cite{ember_brazil_2024, ember_eu_2026}, o Brasil alcançou a marca histórica em que a geração eólica e solar fotovoltaica combinadas ultrapassam um terço da eletricidade produzida no país \cite{ember_brazil_2024}, conforme ilustrado na Figura \ref{fig:grafico_ember}. Paralelamente, na União Europeia, as fontes renováveis atingiram cerca de 30\% da matriz elétrica \cite{ember_eu_2026}. Com o crescimento exponencial da capacidade instalada, torna-se crítico assegurar que esses ativos operem com o máximo aproveitamento energético possível.

\begin{figure}[htbp]
    \centering
    
    \caption{Geração elétrica renovável no Brasil, evidenciando o crescimento de eólica e solar.}
    \label{fig:grafico_ember}
    \centerline{\small Fonte: Adaptado de Ember (2024).}
\end{figure}

Apesar dos avanços tecnológicos nos materiais semicondutores, a eficiência operacional de um módulo fotovoltaico é drasticamente degradada por variáveis externas em campo. O primeiro fator crítico é o acúmulo de poeira, pólen, dejetos e poluentes suspensos no ar na superfície de vidro do painel, fenômeno conhecido na literatura como \textit{soiling} \cite{qi2025}. A poeira depositada obstrui a radiação solar direta que penetra nas junções p-n, diminuindo a corrente gerada. Estudos apontam que o acúmulo contínuo de poeira pode reduzir a eficiência do painel em até 7,84\% por semana em locais de alta taxa de deposição, podendo ultrapassar 50\% de perda total em períodos de seca prolongada sem intervenção humana ou precipitações pluviométricas de volume adequado \cite{qi2025}. O impacto negativo do acúmulo de sujidade na potência máxima de saída das células fotovoltaicas está quantificado graficamente na Figura \ref{fig:grafico_soiling}.

\begin{figure}[htbp]
    \centering
    
    \caption{Gráfico representativo das perdas na potência de saída em função da deposição de poeira ao longo de períodos secos.}
    \label{fig:grafico_soiling}
    \centerline{\small Fonte: Adaptado de Qi et al. (2025).}
\end{figure}

O segundo fator crítico relaciona-se ao coeficiente de temperatura do silício. O aquecimento natural do painel solar devido à radiação térmica eleva a temperatura de operação muito acima dos 25$^\circ$C padronizados em laboratório. Para cada grau Celsius acrescido à superfície, a potência máxima de saída do painel decresce linearmente entre 0,5\% e 0,6\% \cite{geetha2024}. A deposição de poeira agrava este quadro por atuar como isolante térmico local, mantendo o calor aprisionado sob a camada de sujeira e acelerando a degradação e o envelhecimento do módulo.

Neste cenário, soluções que combinem limpeza automática e arrefecimento ativo demonstram alto potencial técnico e econômico. O presente artigo detalha o desenvolvimento do sistema ASCM, estruturado com foco em baixo custo, sensoriamento em tempo real e facilidade de manutenção mecânica. Adicionalmente, apresenta-se o plano de ensaios práticos que serão executados após a montagem final do protótipo físico para quantificar a taxa exata de atenuação de eficiência do painel e avaliar o desempenho térmico de resfriamento.

\section{Referencial Teórico e Estado da Arte}

\subsection{Mecanismos de Limpeza Ativa e Passiva}

A literatura científica classifica os métodos de higienização de painéis fotovoltaicos em duas principais categorias:
\begin{itemize}
    \item \textbf{Métodos Passivos (Revestimentos):} Utilizam nanotecnologia aplicada à superfície do vidro para formar películas super-hidrofóbicas. Esses revestimentos diminuem o ângulo de contato da água e reduzem as forças de adesão de Van der Waals das partículas de poeira \cite{qi2025}. Embora promissores, apresentam custo elevado de aplicação e vida útil curta sob intempéries e abrasão mecânica.
    \item \textbf{Métodos Ativos (Mecânicos e Pneumáticos):} Compreendem sistemas que despendem energia para a remoção da poeira. Os robôs autônomos utilizam esteiras e escovas rotativas para transladar entre painéis. Entretanto, sua complexidade e custo são proibitivos para instalações de pequeno e médio porte. Os sistemas de aspersão com bicos aspersores combinados a rodos motorizados (\textit{wipers}) destacam-se pelo equilíbrio entre custo de instalação e alta eficácia. Estudos práticos realizados por Geetha et al. \cite{geetha2024} indicaram um aumento real de 14,81\% na potência de saída utilizando esta abordagem de aspersão com limpeza mecânica controlada por microcontrolador.
\end{itemize}

\subsection{O Fenômeno de Cristalização de Sujeira (\textit{Dust Scaling})}

Estudos de Qi et al. \cite{qi2025} apontam que a interação da poeira seca com a umidade do ar (como o orvalho matinal) é responsável pelo fenômeno de \textit{dust scaling} ou formação de crosta rígida (\textit{hard scale}). Quando a umidade relativa situa-se na faixa entre 40\% e 80\%, formam-se pontes de água microscópicas por capilaridade entre as partículas de poeira e o vidro. Após o nascer do sol e subsequente evaporação da água, sais minerais solúveis cristalizam-se, cimentando a sujeira na superfície. A remoção de tal camada torna-se inviável por meio de métodos puramente a seco (como sopro de ar ou escovação seca simples), exigindo o uso controlado de água como solvente mecânico aliado ao atrito de um rodo.

\subsection{Gestão Hídrica}

Um desafio frequente na higienização por aspersão é o consumo de água, elemento que pode impactar negativamente a sustentabilidade ecológica e econômica do projeto. Autores como Cavalcante et al. \cite{cavalcante2016} propõem a implementação de captação de água pluvial conjugada a filtros físicos de sedimentação e filtragem de partículas grossas e finas no reservatório do próprio sistema fotovoltaico. Tal abordagem reduz o consumo líquido de água potável da rede de distribuição a níveis próximos de zero, viabilizando o sistema para regiões semiáridas ou remotas.

\section{Metodologia e Arquitetura do ASCM}

O protótipo do sistema ASCM foi desenvolvido utilizando componentes comerciais de prateleira (COTS - \textit{Commercial Off-The-Shelf}) visando manter a replicabilidade e o baixo custo de fabricação. A arquitetura divide-se nas seções de Hardware, Software de Supervisão e Estratégia de Controle.

\subsection{Especificação e Arquitetura de Hardware}

O hardware eletrônico está centrado no microcontrolador Arduino Uno R3. A pinagem completa e o barramento do protótipo estão estruturados conforme detalhado no Guia de Hardware \cite{electronics_guide}. As conexões principais consistem em:
\begin{itemize}
    \item \textbf{Aquisição de Potência Elétrica (Sensores INA219):} Dois módulos INA219 integrados via barramento de comunicação $I^2C$ realizam a medição bidirecional de corrente e tensão. O sensor principal (endereço original $0x40$) monitora o painel limpo pelo sistema. O segundo sensor (endereço $0x41$, configurado via ponte de solda no pino de endereço A0) monitora o painel de referência, que permanecerá exposto ao acúmulo de sujeira natural. Ambas as saídas dos painéis são aplicadas sobre resistores de carga de 33 $\Omega$ e potência mínima de 1.5W para simular o consumo constante de carga.
    \item \textbf{Sensoriamento de Condições Ambientais:} Um sensor analógico de luz (resistor dependente de luz - LDR) associado a um divisor de tensão de 10 k$\Omega$ é lido pela porta analógica A0 para estimar a irradiância luminosa relativa. A medição térmica da superfície do painel é realizada por meio de um termopar LM35 montado na face traseira do painel, lido pela porta analógica A1.
    \item \textbf{Atuadores Eletromecânicos:} O rodo mecânico é movido linearmente por um motor de corrente contínua (DC) acoplado a uma redução mecânica. O acionamento da velocidade do motor é feito via sinal PWM pelo pino 11, e o sentido de movimentação é comandado pelos pinos digitais 9 e 10 de um driver Ponte H L298N. Chaves fim de curso do tipo \textit{micro-switch} estão instaladas no início (pino digital 2, \textit{Home}) e fim (pino digital 3, \textit{End}) do trilho de deslizamento.
    \item \textbf{Subsistema Hidráulico:} Consiste em uma mini-bomba d'água submersível de 5V controlada via driver L298N (pino PWM 6 para fluxo e pinos digitais 7 e 8 para sentido/ativação) ligada a bicos aspersores instalados no topo do painel principal para nebulizar o fluido na superfície do vidro.
\end{itemize}

A alimentação de energia da ponte H é provida de forma externa por uma fonte de alimentação CC de 5V dedicada para motores e bomba, compartilhando a mesma referência de terra (GND) com o microcontrolador Arduino. O diagrama de conexões elétricas e esquemático do protótipo eletrônico de montagem está ilustrado na Figura \ref{fig:diagrama_eletronica}.

\begin{figure}[htbp]
    \centering
    
    \caption{Diagrama de conexões elétricas e esquemático de montagem física dos componentes eletrônicos do ASCM.}
    \label{fig:diagrama_eletronica}
    \centerline{\small Fonte: Elaborado pelos autores.}
\end{figure}

\subsection{Design Mecânico e Modelagem 3D}

O design estrutural e o mecanismo de movimentação linear do ASCM foram totalmente modelados utilizando o software de CAD tridimensional Autodesk Inventor, visando a prototipagem rápida através da fabricação por manufatura aditiva (impressão 3D por deposição de material fundido - FDM). O design mecânico compreende a modelagem dos seguintes componentes principais:
\begin{itemize}
    \item \textbf{Mecanismo de Transmissão por Pinhão e Cremalheira (Gear and Rack):} Para evitar deslizamentos mecânicos comuns em transmissões por polia e correia sob condições de umidade e exposição direta a respingos de água, o sistema adota um mecanismo de pinhão e cremalheira. A cremalheira (\textit{Gear-Rack}) é fixada ao longo do trilho de deslizamento, e o pinhão (\textit{Gear} acoplado ao eixo do motor DC) engrena diretamente na cremalheira para guiar a translação suave do rodo.
    \item \textbf{Suporte do Rodo (Wiper Support):} Peça personalizada que aloja o motor de tração com redução e fixa a haste do rodo de silicone contra a superfície do vidro do painel principal, garantindo uma pressão de contato uniforme para a varredura da poeira.
    \item \textbf{Suporte de Aspersão (Sprinkler Support):} Fixadores posicionados no topo do painel que sustentam a tubulação hidráulica e os bicos aspersores orientados em ângulo que maximiza a área de cobertura da lâmina d'água na superfície.
    \item \textbf{Suportes dos Painéis (Panel Support):} Peças de interface que prendem os módulos fotovoltaicos de forma rígida à estrutura de suporte principal.
\end{itemize}
A modelagem em CAD de todas as peças foi exportada em formato STL para fabricação por manufatura aditiva. Para a confecção do protótipo físico de teste, utilizou-se filamento de PLA (Ácido Polilático) pela facilidade de prototipagem rápida e baixo custo, embora materiais como PETG ou ABS possam ser aplicados em versões finais expostas a intempéries contínuas caso o equipamento de impressão ofereça suporte a tais polímeros. A vista explodida da montagem, evidenciando o encaixe entre a cremalheira linear, o pinhão e o suporte do rodo motorizado, está ilustrada na Figura \ref{fig:vista_explodida}.

\begin{figure}[htbp]
    \centering
    \IfFileExists{images/vista_explodida.png}{%
        %
    }{%
        \fbox{\parbox[c][6cm][c]{0.9\textwidth}{\centering\textit{Vista explodida da montagem (pendente)}}}%
    }
    \caption{Vista explodida da montagem do mecanismo de translação do ASCM: (1) Cremalheira (\textit{Gear-Rack}); (2) Pinhão (\textit{Gear}); (3) Suporte do Rodo (\textit{Wiper Support}); (4) Suporte de Aspersão (\textit{Sprinkler}); (5) Suporte dos Painéis (\textit{Panel Support}).}
    \label{fig:vista_explodida}
    \centerline{\small Fonte: Elaborado pelos autores.}
\end{figure}

\subsection{Arquitetura do Software e Comunicação}

Ao contrário de abordagens convencionais com firmware C/C++ estático compilado no Arduino, o ASCM adota a arquitetura **Telemetrix** \cite{telemetrix_ref}. O Arduino Uno executa o sketch padrão \textit{Telemetrix4Arduino}, operando puramente como um dispositivo escravo de entrada e saída (servidor de I/O) que se comunica via porta serial com um computador hospedeiro. 

Toda a lógica de controle complexa, o tratamento matemático e os logs são implementados na linguagem Python no computador servidor:
\begin{enumerate}
    \item \textbf{Backend (FastAPI):} Desenvolve o controle centralizado de eventos e automatiza o laço periódico. Ele atualiza leituras analógicas e digitais usando callbacks rápidos implementados no Telemetrix, e interroga os sensores $I^2C$ de potência INA219. O laço síncrono também interage com uma API de meteorologia online para coletar a temperatura ambiente local e checar a incidência de chuvas no momento. Os logs de telemetria e eventos são exportados periodicamente para arquivos CSV estruturados.
    \item \textbf{Frontend (Streamlit):} Provê uma interface web simplificada para o monitoramento instantâneo do sistema. O dashboard apresenta de forma intuitiva as grandezas elétricas de geração (tensão, corrente, potência), a temperatura da superfície e a diferença percentual de rendimento devido ao \textit{soiling}, além de permitir comandos manuais de emergência (parada total, ativação forçada de bomba ou motor).
\end{enumerate}

\subsection{Estratégia do Laço de Controle Automatizado}

A estratégia de automação funciona em ciclo contínuo em segundo plano e adota dois gatilhos paralelos e complementares:
\begin{enumerate}
    \item \textbf{Algoritmo de Resfriamento Térmico:} A temperatura da superfície do painel fotovoltaico ($T_{painel}$) é medida pelo termopar LM35 e comparada com a temperatura ambiente real ($T_{amb}$) retornada pelo serviço de meteorologia. O resfriamento é disparado se:
    \begin{equation}
        T_{painel} > T_{amb} + \Delta T_{lim}
    \end{equation}
    onde $\Delta T_{lim}$ é o diferencial limite definido no sistema (padrão de 5$^\circ$C). A bomba de água é acionada em modo de fluxo alto por um período programado até que a temperatura do painel se estabilize abaixo do limiar.
    \item \textbf{Algoritmo de Higienização de Sujeira:} A potência gerada pelo painel principal ($P_{main}$) e pelo painel de referência dirty ($P_{ref}$) são calculadas pelos respectivos sensores de potência INA219. A perda percentual por \textit{soiling} ($\Delta \eta$) é dada por:
    \begin{equation}
        \Delta \eta = \left( \frac{P_{ref} - P_{main}}{P_{ref}} \right) \times 100\%
    \end{equation}
    Se $\Delta \eta > \eta_{lim}$ (onde $\eta_{lim}$ é o limiar de sujeira tolerado, tipicamente 10\%) e a API de clima indicar que não há precipitação de chuva em andamento, o backend FastAPI invoca a tarefa assíncrona de ciclo de limpeza completo:
    \begin{itemize}
        \item Ativação da bomba d'água em fluxo baixo para molhar a poeira e amolecer o \textit{hard scale} por 2 segundos.
        \item Deslocamento do rodo mecânico na direção progressiva (\textit{forward}) com velocidade controlada via PWM até atingir a chave fim de curso final (\textit{limit\_end}).
        \item Breve pausa de 1 segundo e subsequente reversão do motor na direção contrária (\textit{backward}) até pressionar a chave fim de curso inicial (\textit{limit\_home}).
        \item Desligamento do motor e da bomba hidráulica, retornando o sistema ao monitoramento em malha fechada.
    \end{itemize}
\end{enumerate}

A lógica de funcionamento integrada de controle periódico, monitoramento de limites e acionamentos automáticos baseados nas decisões térmicas e de sujeira é apresentada no fluxograma de controle da Figura \ref{fig:fluxograma_controle}.

\begin{figure}[htbp]
    \centering
    
    \caption{Fluxograma do laço de controle de automação e de tomada de decisão do sistema ASCM.}
    \label{fig:fluxograma_controle}
    \centerline{\small Fonte: Elaborado pelos autores.}
\end{figure}

\section{Resultados Preliminares e Metodologia de Ensaios}

Esta seção descreve a validação inicial do software de controle e detalha a metodologia projetada para os futuros ensaios empíricos com o protótipo físico completo montado.

\subsection{Validação do Loop de Automação de Software}

Durante as simulações do software de controle, as rotinas de callback do Telemetrix integradas à biblioteca FastAPI demonstraram latência inferior a 15 ms para detecção das chaves fim de curso, garantindo uma parada de emergência segura para os motores de movimentação linear do rodo. As leituras em barramento compartilhado dos sensores INA219 a frequências de amostragem de 1 Hz mostraram-se estáveis, com flutuações de corrente e tensão inferiores a 1,2\%, adequadas para o cálculo preciso do rendimento diferencial.

\subsection{Metodologia para Ensaio Físico e Acúmulo de Poeira (\textit{Soiling})}

Com a montagem do protótipo físico completo em andamento, será conduzido um ensaio experimental com o objetivo de levantar a curva de diminuição da eficiência energética devido ao acúmulo de sujeira. Este ensaio de campo, de longo prazo (30 dias) e sujeira natural, representa a validação definitiva do sistema em condições reais de operação, e é complementar ao ensaio de curto prazo em ambiente controlado com luz artificial e sujeira induzida, conduzido como validação preliminar do laço de automação. O procedimento do ensaio seguirá as seguintes etapas:
\begin{enumerate}
    \item Ambos os painéis (principal e referência) serão instalados externamente em suporte ajustável, expostos sob as mesmas condições de inclinação, orientação geográfica e sombreamento.
    \item No dia inicial ($t=0$), ambos os painéis serão limpos manualmente com água deionizada para garantir calibração inicial idêntica ($P_{main} \approx P_{ref}$).
    \item O painel de referência será mantido sob exposição ao acúmulo natural de poeira local por um período contínuo de 30 dias, sem passar por nenhum ciclo de limpeza automática.
    \item O painel principal passará pela automação do ASCM, disparando ciclos de limpeza sempre que a diferença de potência ultrapassar o limiar programado ($\eta_{lim} = 10\%$).
    \item Os parâmetros de geração (tensão, corrente, potência de pico e energia diária acumulada) serão registrados minuto a minuto para ambos os painéis. A irradiância local relativa será monitorada via LDR.
\end{enumerate}

\subsection{Placeholder para Resultados Experimentais Futuros}

A Tabela \ref{tab:ensaio_soiling} apresenta o modelo estrutural de dados que será preenchido para documentar a atenuação de eficiência e avaliar os ganhos trazidos pelo acionamento periódico do sistema ASCM.

\begin{table}[htbp]
    \centering
    \caption{Estrutura de dados para o ensaio de degradação por \textit{soiling} (a ser preenchida após ensaio).}
    \label{tab:ensaio_soiling}
    \begin{tabular}{cccccc}
    \toprule
    \textbf{Dia} & \textbf{Luminosidade (LDR)} & \textbf{Potência Principal ($P_{main}$)} & \textbf{Potência Ref. ($P_{ref}$)} & \textbf{Perda Diferencial ($\Delta \eta$)} & \textbf{Status da Limpeza} \\
    \midrule
    0 & --- & [A ser inserido] & [A ser inserido] & 0.0\% & Calibrado \\
    5 & --- & [A ser inserido] & [A ser inserido] & [A ser inserido] & --- \\
    10 & --- & [A ser inserido] & [A ser inserido] & [A ser inserido] & --- \\
    15 & --- & [A ser inserido] & [A ser inserido] & [A ser inserido] & --- \\
    20 & --- & [A ser inserido] & [A ser inserido] & [A ser inserido] & --- \\
    25 & --- & [A ser inserido] & [A ser inserido] & [A ser inserido] & --- \\
    30 & --- & [A ser inserido] & [A ser inserido] & [A ser inserido] & Finalizado \\
    \bottomrule
    \end{tabular}
\end{table}

\subsection{Ensaio de Arrefecimento e Ganho de Potência por Resfriamento}

Além do ensaio de sujidade, o termopar LM35 em conjunto com a bomba aspersora possibilitará a realização do ensaio térmico. Sob irradiância solar máxima no período do meio-dia (onde o painel atinge temperaturas elevadas superiores a 50$^\circ$C), o resfriamento evaporativo será acionado. Será mapeada a curva de queda de temperatura vs o ganho de potência instantânea resultante. Os resultados esperados, embasados na literatura, preveem uma redução térmica estável de 5$^\circ$C a 10$^\circ$C na temperatura de operação das células, correspondendo a uma recuperação linear de potência entre 2.5\% e 6.0\% no instante de resfriamento.

\section{Conclusão e Próximos Passos}

O protótipo do ASCM projetado demonstrou-se viável sob o aspecto de desenvolvimento de software e integração de hardware de baixo custo, orçando um custo total de montagem inferior ao de soluções industriais. O uso do protocolo Telemetrix permitiu a criação de um laço de automação flexível e centralizado no computador hospedeiro via FastAPI e Streamlit.

Os próximos passos deste trabalho consistem no término do acoplamento mecânico estrutural do rodo impresso em 3D no painel solar físico e no início imediato dos ensaios de degradação por sujidade de 30 dias e testes térmicos. Espera-se com esses testes validar a eficácia prática da aspersão com raspagem mecânica na remoção de poeira consolidada (\textit{hard scale}) e no ganho líquido anual de geração elétrica do sistema.

\bibliographystyle{plain}
\bibliography{CONICT/bibliografia}

\end{document}

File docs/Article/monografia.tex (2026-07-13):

\documentclass[12pt, a4paper]{article}

\usepackage[utf8]{inputenc}
\usepackage[T1]{fontenc}
\usepackage[brazil]{babel}
\usepackage{geometry}
\geometry{a4paper, margin=3cm}
\usepackage{graphicx}
\usepackage{amsmath}
\usepackage{booktabs}
\usepackage{longtable}
\usepackage{hyperref}
\usepackage{cite}
\usepackage{xcolor}

\graphicspath{{./}{./images/}}

\hypersetup{
    colorlinks=true,
    linkcolor=blue,
    filecolor=magenta,
    urlcolor=cyan,
    citecolor=blue,
}

\title{
    \vspace{-1.5cm}
    \textbf{Sistema Automatizado de Limpeza e Arrefecimento de Painéis Fotovoltaicos (ASCM):\\
    Projeto, Implementação e Metodologia de Validação}
}

\author{
    César Kerber \\
    Lucas Ekroth \\
    Paulo Rangel \\
    \vspace{0.2cm}
    \small Curso de Engenharia de Controle e Automação \\
    \small Instituto Federal de Educação, Ciência e Tecnologia de São Paulo (IFSP) \\
    \small Câmpus São José dos Campos \\
    \small Orientador: Prof. Valdeci Donizete Gonçalves
}

\date{\today}

\begin{document}

\maketitle

\begin{abstract}
\noindent A eficiência de sistemas solares fotovoltaicos é severamente afetada por fatores ambientais externos, sendo o acúmulo de sujeira (\textit{soiling}) e o superaquecimento das células os dois principais fatores de perda de geração. Este trabalho apresenta o desenvolvimento completo de um protótipo de Sistema Automatizado de Limpeza e Arrefecimento de Painéis Fotovoltaicos (\textit{Automated Self-Cleaning and Cooling Mechanism} - ASCM), cobrindo desde o referencial teórico e o projeto mecânico em CAD até a arquitetura de software completa (firmware, backend e dashboard) e a metodologia experimental de validação. O sistema realiza a limpeza mecânica por meio de aspersão de água combinada com um rodo motorizado, e o resfriamento evaporativo por meio do acionamento de uma mini-bomba hidráulica. A lógica de controle é baseada em microcontrolador Arduino Uno rodando o protocolo Telemetrix, integrado a um backend em Python (FastAPI) responsável pela automação, persistência de dados e integração com serviços meteorológicos externos, e a um dashboard em Streamlit para monitoramento e controle manual em tempo real. O acionamento da limpeza é guiado de forma inteligente pela comparação diferencial de potência entre um painel principal e um painel de referência mantido sujo. Este documento detalha, em profundidade, cada subsistema do ASCM — eletrônica, mecânica, firmware, API REST e interface de usuário — além de estabelecer a metodologia para os ensaios de curto e longo prazo que validarão a remoção de sujidade induzida, a recuperação de eficiência e o ganho térmico do protótipo completo.
\end{abstract}

\textbf{Palavras-chave:} Energia Solar Fotovoltaica. Soiling. Arrefecimento Térmico. Automação. Arduino. FastAPI. Streamlit.

\newpage
\tableofcontents
\newpage

\section{Introdução}

\subsection{Contextualização}

A transição energética global em direção a fontes renováveis tem posicionado a energia solar fotovoltaica como um dos pilares fundamentais da matriz elétrica de diversos países. Segundo relatórios da organização de estudos energéticos \textit{Ember} \cite{ember_brazil_2024, ember_eu_2026}, o Brasil alcançou a marca histórica em que a geração eólica e solar fotovoltaica combinadas ultrapassam um terço da eletricidade produzida no país \cite{ember_brazil_2024}, conforme ilustrado na Figura \ref{fig:grafico_ember}. Paralelamente, na União Europeia, as fontes renováveis atingiram cerca de 30\% da matriz elétrica \cite{ember_eu_2026}. Com o crescimento exponencial da capacidade instalada, torna-se crítico assegurar que esses ativos operem com o máximo aproveitamento energético possível, uma vez que perdas percentuais pequenas, quando multiplicadas pela escala de gigawatts instalados, representam quantidades significativas de energia não gerada.

\begin{figure}[htbp]
    \centering
    
    \caption{Geração elétrica renovável no Brasil, evidenciando o crescimento de eólica e solar.}
    \label{fig:grafico_ember}
    \centerline{\small Fonte: Adaptado de Ember (2024).}
\end{figure}

Apesar dos avanços tecnológicos nos materiais semicondutores, a eficiência operacional de um módulo fotovoltaico é drasticamente degradada por variáveis externas em campo. O primeiro fator crítico é o acúmulo de poeira, pólen, dejetos e poluentes suspensos no ar na superfície de vidro do painel, fenômeno conhecido na literatura como \textit{soiling} \cite{qi2025}. A poeira depositada obstrui a radiação solar direta que penetra nas junções p-n, diminuindo a corrente gerada. Estudos apontam que o acúmulo contínuo de poeira pode reduzir a eficiência do painel em até 7,84\% por semana em locais de alta taxa de deposição, podendo ultrapassar 50\% de perda total em períodos de seca prolongada sem intervenção humana ou precipitações pluviométricas de volume adequado \cite{qi2025}. O impacto negativo do acúmulo de sujidade na potência máxima de saída das células fotovoltaicas está quantificado graficamente na Figura \ref{fig:grafico_soiling}.

\begin{figure}[htbp]
    \centering
    
    \caption{Gráfico representativo das perdas na potência de saída em função da deposição de poeira ao longo de períodos secos.}
    \label{fig:grafico_soiling}
    \centerline{\small Fonte: Adaptado de Qi et al. (2025).}
\end{figure}

O segundo fator crítico relaciona-se ao coeficiente de temperatura do silício. O aquecimento natural do painel solar devido à radiação térmica eleva a temperatura de operação muito acima dos 25$^\circ$C padronizados em laboratório. Para cada grau Celsius acrescido à superfície, a potência máxima de saída do painel decresce linearmente entre 0,5\% e 0,6\% \cite{geetha2024}. A deposição de poeira agrava este quadro por atuar como isolante térmico local, mantendo o calor aprisionado sob a camada de sujeira e acelerando a degradação e o envelhecimento do módulo.

\subsection{Justificativa}

Diante desse cenário, soluções de baixo custo que combinem limpeza automática e arrefecimento ativo apresentam alto potencial técnico e econômico, sobretudo para instalações de pequeno e médio porte (residenciais e pequenos comércios), onde soluções industriais de limpeza robotizada são financeiramente inviáveis. A escolha por uma arquitetura baseada em componentes comerciais de prateleira (COTS), microcontrolador de baixo custo e software livre justifica-se pela necessidade de reprodutibilidade acadêmica e pela possibilidade de escalar o sistema para redes de múltiplos painéis sem custos proibitivos de licenciamento ou hardware proprietário.

\subsection{Objetivos}

\subsubsection{Objetivo Geral}
Desenvolver e validar um protótipo funcional de sistema automatizado de limpeza e arrefecimento de painéis fotovoltaicos (ASCM), capaz de detectar autonomamente a perda de eficiência por \textit{soiling} e por superaquecimento, e reagir com ciclos de limpeza mecânica e resfriamento evaporativo.

\subsubsection{Objetivos Específicos}
\begin{itemize}
    \item Projetar e fabricar, por manufatura aditiva (impressão 3D), o mecanismo eletromecânico de translação do rodo de limpeza;
    \item Especificar e integrar o hardware eletrônico de sensoriamento (potência, temperatura, luminosidade e fins de curso) e atuação (motor DC e bomba hidráulica);
    \item Desenvolver um firmware baseado no protocolo Telemetrix que dispense a necessidade de recompilação para alterações na lógica de controle;
    \item Implementar um backend em Python (FastAPI) responsável pela automação, persistência de telemetria e integração com serviços meteorológicos externos;
    \item Implementar um dashboard web (Streamlit) para monitoramento em tempo real e controle manual de emergência;
    \item Estabelecer e documentar a metodologia de ensaios de curto prazo (ambiente controlado) e de longo prazo (campo) para validação quantitativa do sistema.
\end{itemize}

\subsection{Estrutura do Trabalho}

Este documento está organizado da seguinte forma: a Seção \ref{sec:referencial} apresenta o referencial teórico sobre soiling, arrefecimento térmico e trabalhos correlatos. A Seção \ref{sec:metodologia} detalha a arquitetura completa do sistema — hardware, mecânica, firmware, backend, dashboard e estratégia de controle. A Seção \ref{sec:resultados} apresenta os resultados preliminares de validação de software e a metodologia projetada para os ensaios físicos. Por fim, a Seção \ref{sec:conclusao} apresenta as considerações finais e os próximos passos do projeto.

\section{Referencial Teórico e Estado da Arte}
\label{sec:referencial}

\subsection{Mecanismos de Limpeza Ativa e Passiva}

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

\subsection{O Fenômeno de Cristalização de Sujeira (\textit{Dust Scaling})}

Estudos de Qi et al. \cite{qi2025} apontam que a interação da poeira seca com a umidade do ar (como o orvalho matinal) é responsável pelo fenômeno de \textit{dust scaling} ou formação de crosta rígida (\textit{hard scale}). Quando a umidade relativa situa-se na faixa entre 40\% e 80\%, formam-se pontes de água microscópicas por capilaridade entre as partículas de poeira e o vidro. Após o nascer do sol e subsequente evaporação da água, sais minerais solúveis cristalizam-se, cimentando a sujeira na superfície. A remoção de tal camada torna-se inviável por meio de métodos puramente a seco (como sopro de ar ou escovação seca simples), exigindo o uso controlado de água como solvente mecânico aliado ao atrito de um rodo.

\subsection{Arrefecimento Térmico Ativo}

Sistemas automáticos de limpeza e arrefecimento ativo demonstram-se soluções promissoras e de baixo custo para mitigar as perdas conjuntas de soiling e temperatura \cite{derakhshandeh2021}, inclusive com estratégias de controle dinâmicas baseadas nas condições climáticas em tempo real, como o acompanhamento de previsão de chuva e temperatura ambiente para evitar acionamentos desnecessários \cite{mendis2026}. O resfriamento evaporativo, obtido pela aspersão de uma fina lâmina d'água sobre o vidro do painel, retira calor da superfície tanto pela troca convectiva direta com a água quanto pela evaporação subsequente, sendo uma técnica de baixo custo energético comparada a sistemas de refrigeração ativa (Peltier ou compressores).

\subsection{Gestão Hídrica}

Um desafio frequente na higienização por aspersão é o consumo de água, elemento que pode impactar negativamente a sustentabilidade ecológica e econômica do projeto. Autores como Cavalcante et al. \cite{cavalcante2016} propõem a implementação de captação de água pluvial conjugada a filtros físicos de sedimentação e filtragem de partículas grossas e finas no reservatório do próprio sistema fotovoltaico. Tal abordagem reduz o consumo líquido de água potável da rede de distribuição a níveis próximos de zero, viabilizando o sistema para regiões semiáridas ou remotas.

\subsection{Síntese Comparativa dos Trabalhos Correlatos}

A Tabela \ref{tab:trabalhos_correlatos} sintetiza as principais abordagens discutidas na literatura consultada, contrastando-as com a proposta do ASCM em termos de mecanismo de acionamento, uso de água e integração com sensoriamento inteligente.

\begin{table}[htbp]
    \centering
    \caption{Comparativo entre abordagens de limpeza/arrefecimento na literatura e o ASCM.}
    \label{tab:trabalhos_correlatos}
    \begin{tabular}{p{2.6cm}p{3.6cm}p{2.2cm}p{4.4cm}}
    \toprule
    \textbf{Referência} & \textbf{Mecanismo} & \textbf{Uso de Água} & \textbf{Controle} \\
    \midrule
    Geetha et al. \cite{geetha2024} & Aspersão + limpeza mecânica & Sim & Microcontrolador, acionamento simples \\
    Derakhshandeh et al. \cite{derakhshandeh2021} & Revisão de sistemas automáticos diversos & Variável & Diversos, sem padrão único \\
    Mendis et al. \cite{mendis2026} & Rastreamento solar dual-eixo + autolimpeza & Não especificado & Reativo às condições climáticas em tempo real \\
    Cavalcante et al. \cite{cavalcante2016} & Aspersão com reaproveitamento hídrico & Sim (pluvial) & Manual/temporizado \\
    \textbf{ASCM (este trabalho)} & Aspersão + rodo motorizado (\textit{gear-rack}) & Sim (dosada) & Diferencial de potência entre painéis + API de clima \\
    \bottomrule
    \end{tabular}
\end{table}

Observa-se que a maioria dos trabalhos correlatos aciona a limpeza de forma temporizada ou puramente reativa à temperatura, ao passo que o ASCM soma dois critérios independentes (perda diferencial de potência e previsão de chuva) para decidir o acionamento, reduzindo o desperdício de água em ciclos desnecessários.

\section{Materiais e Métodos}
\label{sec:metodologia}

O protótipo do sistema ASCM foi desenvolvido utilizando componentes comerciais de prateleira (COTS - \textit{Commercial Off-The-Shelf}) visando manter a replicabilidade e o baixo custo de fabricação. A arquitetura divide-se em: Hardware Eletrônico, Projeto Mecânico, Firmware, Backend, Dashboard e Estratégia de Controle.

\subsection{Visão Geral da Arquitetura}

A Figura \ref{fig:fluxograma_controle} (Seção \ref{sec:estrategia-controle}) resume o funcionamento macro do sistema: sensores conectados ao Arduino Uno alimentam, via protocolo serial Telemetrix, um backend Python que centraliza a lógica de decisão, persiste os dados e expõe uma API REST consumida tanto pelo laço de automação interno quanto pelo dashboard Streamlit usado pelo operador humano.

\subsection{Especificação e Arquitetura de Hardware}

O hardware eletrônico está centrado no microcontrolador Arduino Uno R3. A Tabela \ref{tab:bom} apresenta a lista de materiais (BOM) do protótipo, e a Tabela \ref{tab:pinout} detalha o mapeamento de pinos utilizado, ambos documentados de forma exaustiva no Guia de Hardware do projeto \cite{electronics_guide}.

\begin{table}[htbp]
    \centering
    \caption{Lista de materiais (BOM) do protótipo ASCM.}
    \label{tab:bom}
    \begin{tabular}{p{3.2cm}p{1.2cm}p{4.0cm}p{4.4cm}}
    \toprule
    \textbf{Item} & \textbf{Qtd.} & \textbf{Descrição} & \textbf{Função} \\
    \midrule
    Microcontrolador & 1 & Arduino Uno R3 & Interface de I/O (firmware Telemetrix) \\
    Driver de Motor & 1 & Ponte H L298N & Controle do motor de movimentação (\textit{wiper}) \\
    Motor DC & 1 & Motor 5V com redução & Movimentação da escova/rodo \\
    Bomba d'água & 1 & Mini-bomba submersível 5V & Aspersão e arrefecimento \\
    Sensores de Potência & 2 & Módulo INA219 ($I^2C$) & Monitoramento de V/I do painel principal e de referência \\
    Sensores Fim de Curso & 2 & Micro-switch (NF/NA) & Limitação física do curso do rodo \\
    Sensor de Temperatura & 1 & Termopar/LM35 & Monitoramento térmico da superfície \\
    Sensor de Luz & 1 & LDR & Medição de irradiância relativa \\
    Resistor de Carga & 2 & 33 $\Omega$ ($\geq$ 1,5W) & Carga para medição de potência dos painéis \\
    Resistor LDR & 1 & 10 k$\Omega$ & Divisor de tensão do LDR \\
    Painel Solar & 2 & Módulos fotovoltaicos & Geração de energia e referência de sujeira \\
    \bottomrule
    \end{tabular}
\end{table}

\begin{table}[htbp]
    \centering
    \caption{Mapeamento de pinos (\textit{pinout}) do Arduino Uno no protótipo ASCM.}
    \label{tab:pinout}
    \begin{tabular}{p{4.2cm}p{1.6cm}p{2.0cm}p{5.0cm}}
    \toprule
    \textbf{Componente} & \textbf{Pino} & \textbf{Tipo} & \textbf{Descrição} \\
    \midrule
    Ponte H (ENA) & 11 & PWM & Velocidade do motor (\textit{wiper}) \\
    Ponte H (IN1) & 9 & Digital & Direção do motor (\textit{wiper}) \\
    Ponte H (IN2) & 10 & Digital & Direção do motor (\textit{wiper}) \\
    Ponte H (ENB) & 6 & PWM & Velocidade/fluxo da bomba \\
    Ponte H (IN3) & 7 & Digital & Ativação da bomba \\
    Ponte H (IN4) & 8 & Digital & Ativação da bomba \\
    Fim de Curso (Home) & 2 & Digital & Sensor de posição inicial \\
    Fim de Curso (End) & 3 & Digital & Sensor de posição final \\
    LDR & A0 & Analógico & Leitura de luminosidade \\
    Temperatura & A1 & Analógico & Leitura de temperatura da superfície \\
    INA219 Principal & A4/A5 & $I^2C$ (0x40) & Painel monitorado/limpo pelo sistema \\
    INA219 Referência & A4/A5 & $I^2C$ (0x41) & Painel de referência (sujeira natural) \\
    \bottomrule
    \end{tabular}
\end{table}

O sensor principal (endereço $I^2C$ $0x40$) monitora o painel limpo pelo sistema, enquanto o segundo sensor (endereço $0x41$, obtido por meio de uma ponte de solda no pino de endereço A0 do módulo) monitora o painel de referência, mantido propositalmente sujo. Ambas as saídas dos painéis são aplicadas sobre resistores de carga de 33 $\Omega$ e potência mínima de 1,5W para simular o consumo constante de carga. A alimentação de potência da Ponte H é provida externamente por uma fonte CC de 5V dedicada a motores e bomba, compartilhando a mesma referência de terra (GND) com o Arduino. O diagrama de conexões elétricas está ilustrado na Figura \ref{fig:diagrama_eletronica}.

\begin{figure}[htbp]
    \centering
    
    \caption{Diagrama de conexões elétricas e esquemático de montagem física dos componentes eletrônicos do ASCM.}
    \label{fig:diagrama_eletronica}
    \centerline{\small Fonte: Elaborado pelos autores.}
\end{figure}

\subsection{Projeto Mecânico e Modelagem 3D}

O design estrutural e o mecanismo de movimentação linear do ASCM foram totalmente modelados utilizando o software de CAD tridimensional Autodesk Inventor, visando a prototipagem rápida através da fabricação por manufatura aditiva (impressão 3D por deposição de material fundido - FDM). O design mecânico compreende a modelagem dos seguintes componentes principais:
\begin{itemize}
    \item \textbf{Mecanismo de Transmissão por Pinhão e Cremalheira (\textit{Gear and Rack}):} Para evitar deslizamentos mecânicos comuns em transmissões por polia e correia sob condições de umidade e exposição direta a respingos de água, o sistema adota um mecanismo de pinhão e cremalheira. A cremalheira (\textit{Gear-Rack}) é fixada ao longo do trilho de deslizamento, e o pinhão (\textit{Gear} acoplado ao eixo do motor DC) engrena diretamente na cremalheira para guiar a translação suave do rodo.
    \item \textbf{Suporte do Rodo (\textit{Wiper Support}):} Peça personalizada que aloja o motor de tração com redução e fixa a haste do rodo de silicone contra a superfície do vidro do painel principal, garantindo uma pressão de contato uniforme para a varredura da poeira.
    \item \textbf{Suporte de Aspersão (\textit{Sprinkler Support}):} Fixadores posicionados no topo do painel que sustentam a tubulação hidráulica e os bicos aspersores orientados em ângulo que maximiza a área de cobertura da lâmina d'água na superfície.
    \item \textbf{Suportes dos Painéis (\textit{Panel Support}):} Peças de interface que prendem os módulos fotovoltaicos de forma rígida à estrutura de suporte principal.
\end{itemize}
A modelagem em CAD de todas as peças foi exportada em formato STL para fabricação por manufatura aditiva. Para a confecção do protótipo físico de teste, utilizou-se filamento de PLA (Ácido Polilático) pela facilidade de prototipagem rápida e baixo custo, embora materiais como PETG ou ABS possam ser aplicados em versões finais expostas a intempéries contínuas caso o equipamento de impressão ofereça suporte a tais polímeros. A vista explodida da montagem, evidenciando o encaixe entre a cremalheira linear, o pinhão e o suporte do rodo motorizado, está ilustrada na Figura \ref{fig:vista_explodida}.

\begin{figure}[htbp]
    \centering
    \IfFileExists{images/vista_explodida.png}{%
        %
    }{%
        \fbox{\parbox[c][6cm][c]{0.9\textwidth}{\centering\textit{Vista explodida da montagem (pendente)}}}%
    }
    \caption{Vista explodida da montagem do mecanismo de translação do ASCM: (1) Cremalheira (\textit{Gear-Rack}); (2) Pinhão (\textit{Gear}); (3) Suporte do Rodo (\textit{Wiper Support}); (4) Suporte de Aspersão (\textit{Sprinkler}); (5) Suporte dos Painéis (\textit{Panel Support}).}
    \label{fig:vista_explodida}
    \centerline{\small Fonte: Elaborado pelos autores.}
\end{figure}

\subsection{Arquitetura de Software}

Ao contrário de abordagens convencionais com firmware C/C++ estático compilado no Arduino, o ASCM adota a arquitetura \textbf{Telemetrix} \cite{telemetrix_ref, telemetrix_doc}. O Arduino Uno executa o sketch padrão \textit{Telemetrix4Arduino}, operando puramente como um dispositivo escravo de entrada e saída (servidor de I/O) que se comunica via porta serial com um computador hospedeiro. Toda a lógica de controle complexa, o tratamento matemático e os registros de log são implementados na linguagem Python no computador servidor, dividida em três camadas: firmware/driver de hardware, backend (API) e frontend (dashboard).

\subsubsection{Camada de Hardware (\texttt{HardwareManager})}

A classe \texttt{HardwareManager} encapsula toda a comunicação com o Arduino via Telemetrix. Na inicialização, ela configura os modos de pino (saídas digitais para a Ponte H, entradas digitais com \textit{pull-up} para os fins de curso, entradas analógicas para o LDR e o termopar, e o barramento $I^2C$ para os sensores INA219) e registra funções de \textit{callback} assíncronas para cada sensor. As leituras de temperatura e luminosidade passam por um filtro de média móvel com janela de 50 amostras (\texttt{\_temp\_history}, \texttt{\_lux\_history}) para atenuar o ruído inerente às leituras analógicas do LM35 e do LDR. A leitura de potência dos módulos INA219 é feita em duas etapas assíncronas (registrador de tensão de \textit{shunt}, para corrente, e registrador de tensão de barramento, para tensão), sendo a potência instantânea recalculada a cada atualização de tensão recebida.

Os métodos de atuação (\texttt{set\_pump}, \texttt{move\_wiper}, \texttt{stop\_wiper}) implementam trava de segurança por software: o método \texttt{move\_wiper} somente aciona o motor no sentido \textit{forward} se o fim de curso final (\texttt{limit\_end}) ainda não tiver sido atingido, e apenas no sentido \textit{backward} se o fim de curso inicial (\texttt{limit\_home}) ainda estiver aberto, evitando colisões mecânicas mesmo em caso de falha de lógica no nível do backend.

\subsubsection{Backend (FastAPI)}

O backend, implementado com o \textit{framework} FastAPI \cite{fastapi_doc}, expõe uma API REST responsável por três funções centrais: (i) leitura de telemetria em tempo real; (ii) execução de comandos manuais de atuadores; e (iii) execução do laço de automação assíncrono em segundo plano (\texttt{automation\_loop}), que roda a cada 60 segundos e é responsável por registrar a telemetria em disco, avaliar o critério de arrefecimento térmico e avaliar o critério de limpeza por \textit{soiling}. A Tabela \ref{tab:endpoints} documenta todos os \textit{endpoints} disponíveis na API.

\begin{table}[htbp]
    \centering
    \caption{Endpoints da API REST do backend ASCM (FastAPI).}
    \label{tab:endpoints}
    \begin{tabular}{p{1.4cm}p{3.2cm}p{7.2cm}}
    \toprule
    \textbf{Método} & \textbf{Rota} & \textbf{Descrição} \\
    \midrule
    GET & \texttt{/telemetry} & Retorna o estado completo dos sensores em cache (potência dos dois painéis, temperatura, luminosidade, fins de curso, estado da bomba/rodo e flag de limpeza ativa). \\
    GET & \texttt{/weather} & Consulta o serviço meteorológico externo (Open-Meteo) para a latitude/longitude configuradas e retorna temperatura ambiente, umidade, vento e indicação de chuva. \\
    POST & \texttt{/config/update} & Atualiza em tempo real os parâmetros de automação (latitude, longitude, limiar de sujeira, delta de temperatura, habilitação da automação). \\
    POST & \texttt{/cycle/cool} & Aciona manualmente a bomba em fluxo alto para arrefecimento imediato. \\
    POST & \texttt{/cycle/clean} & Dispara, como tarefa em segundo plano, o ciclo completo de limpeza (aspersão + varredura do rodo + retorno). Retorna erro HTTP 409 caso um ciclo já esteja em andamento. \\
    POST & \texttt{/actuators/pump} & Controle manual da bomba, recebendo o nível desejado (\texttt{high}, \texttt{low} ou \texttt{off}). \\
    GET & \texttt{/sensors/temperature} & Retorna isoladamente a temperatura atual da superfície do painel. \\
    GET & \texttt{/sensors/lux} & Retorna isoladamente a leitura de luminosidade relativa (LDR). \\
    GET & \texttt{/sensors/power} & Retorna as grandezas elétricas (tensão, corrente, potência) dos painéis principal e de referência. \\
    POST & \texttt{/actuators/motor} & Controle manual do motor do rodo, recebendo direção (\texttt{forward}/\texttt{backward}) e velocidade PWM opcional. \\
    POST & \texttt{/stop} & Parada de emergência: desliga a bomba e o motor do rodo imediatamente, independentemente do estado do laço de automação. \\
    \bottomrule
    \end{tabular}
\end{table}

O ciclo completo de limpeza, disparado por \texttt{/cycle/clean} ou automaticamente pelo laço de automação, é executado pela função \texttt{run\_full\_clean\_cycle}: a bomba é acionada em fluxo baixo por 2 segundos para umedecer e amolecer o \textit{hard scale}; em seguida o motor do rodo avança até atingir o fim de curso final (com um \textit{timeout} de segurança de 30 segundos contra travamentos mecânicos); o motor é parado por 1 segundo; o motor reverte o sentido até atingir o fim de curso inicial (também com \textit{timeout} de 30 segundos); e, por fim, a bomba e o motor são desligados, encerrando o ciclo.

\paragraph{Persistência e Serviços Auxiliares.} O módulo \texttt{CSVLogger} registra dois arquivos CSV independentes em disco: \texttt{telemetry\_history.csv} (uma linha por ciclo do laço de automação, contendo potência de ambos os painéis, temperatura, luminosidade e estado dos fins de curso) e \texttt{events\_history.csv} (registro cronológico de eventos discretos como início/fim de limpeza, acionamento de arrefecimento e paradas de emergência). O módulo \texttt{WeatherService} consulta a API pública Open-Meteo, sem necessidade de chave de autenticação, retornando temperatura ambiente, umidade relativa, velocidade do vento, pressão e um indicador booleano de chuva (derivado do campo de precipitação instantânea) e de previsão de chuva nas próximas três horas, usado para suprimir ciclos de limpeza que seriam naturalmente executados pela chuva.

\subsubsection{Frontend (Dashboard Streamlit)}

O dashboard, implementado com o \textit{framework} Streamlit \cite{streamlit_doc}, provê uma interface web para monitoramento instantâneo e controle manual do ASCM, consumindo diretamente os \textit{endpoints} da Tabela \ref{tab:endpoints} via requisições HTTP. A Figura \ref{fig:dashboard} apresenta o dashboard renderizado com dados de exemplo, evidenciando suas quatro regiões principais:

\begin{itemize}
    \item \textbf{Barra Lateral (Configurações e Status):} Permite ajustar em tempo real, via \texttt{/config/update}, a latitude/longitude usadas na consulta meteorológica, o limiar percentual de sujeira que dispara a limpeza e o delta de temperatura que dispara o arrefecimento, além de uma chave para habilitar/desabilitar a automação. Também exibe o status bruto dos sensores de fim de curso e um resumo das condições climáticas locais (condição, temperatura externa, vento e umidade), obtidos via \texttt{/telemetry} e \texttt{/weather}.
    \item \textbf{Cabeçalho de Métricas Instantâneas:} Exibe a temperatura do painel (com o delta em relação à temperatura ambiente), a luminosidade relativa e o estado da automação.
    \item \textbf{Comparativo de Geração:} Exibe lado a lado a potência do painel principal e do painel de referência, calculando em tempo real a perda percentual por \textit{soiling} ($\Delta \eta$) e emitindo um alerta visual quando essa perda ultrapassa o limiar configurado.
    \item \textbf{Comandos Manuais e Histórico:} Botões para disparar o ciclo completo de limpeza (\texttt{/cycle/clean}), o arrefecimento isolado (\texttt{/cycle/cool}), o retorno do rodo à posição \textit{home} e a parada de emergência (\texttt{/stop}), todos desabilitados durante um ciclo de limpeza já em andamento para evitar comandos conflitantes. Um gráfico de linha exibe o histórico recente de potência gerada por ambos os painéis.
\end{itemize}
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

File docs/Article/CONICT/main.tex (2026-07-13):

%%%%%%%%%%%%%%%%%%%%%%%%%%%%%%%%%%%%%%%%%%%%%%%%%%%%%%%%%%%%%%%%%%%%%%%%%%%%%%%%%%%%%%%%%%%%%%%%%%%%%%%%%
%Atualizado para o CONICT 2026 - Guarulhos pelo professor João Alves Pacheco
%Data: 06/07/2026
%%%%%%%%%%%%%%%%%%%%%%%%%%%%%%%%%%%%%%%%%%%%%%%%%%%%%%%%%%%%%%%%%%%%%%%%%%%%%%%%%%%%%%%%%%%%%%%%%%%%%%%%%

\documentclass[a4paper,11pt]{article}

\input{preambulo}
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

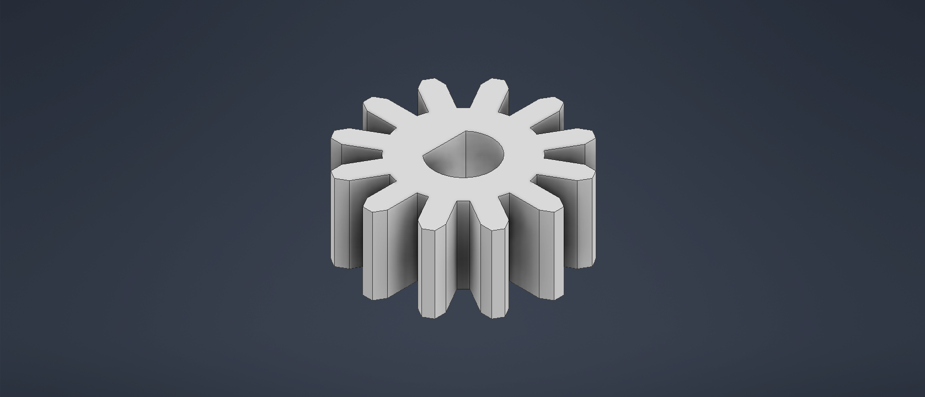
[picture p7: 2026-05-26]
hardware/CAD/images/Gear.png

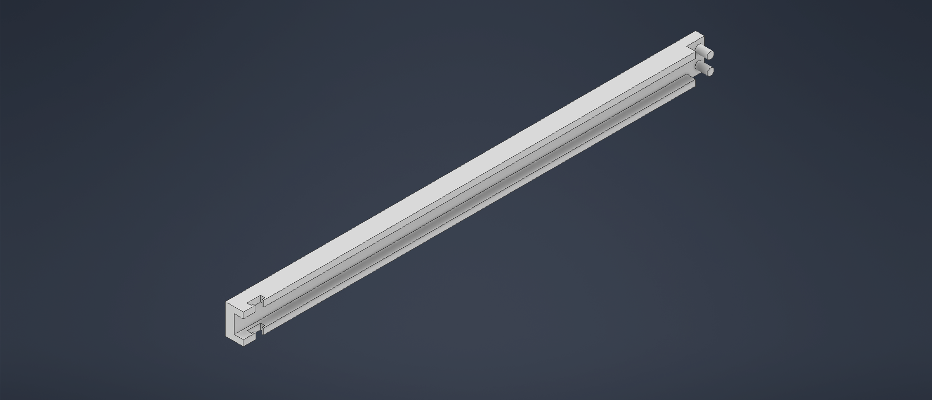
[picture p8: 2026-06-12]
hardware/CAD/images/Wiper-support.png

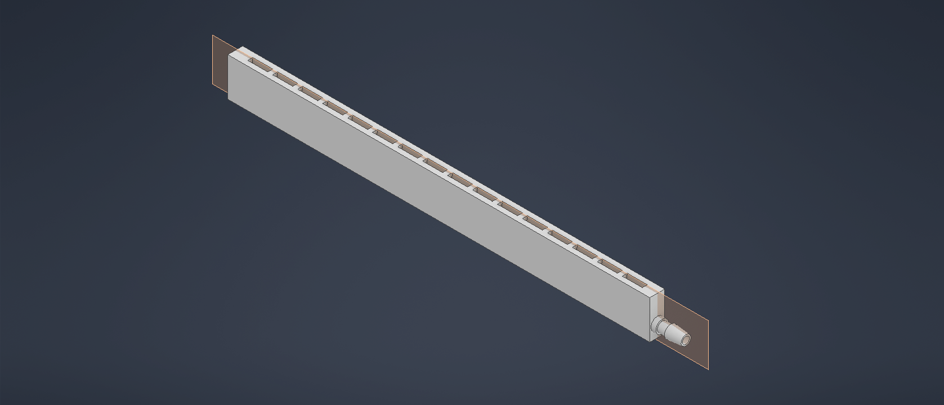
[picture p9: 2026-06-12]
hardware/CAD/images/Sprinkler.png

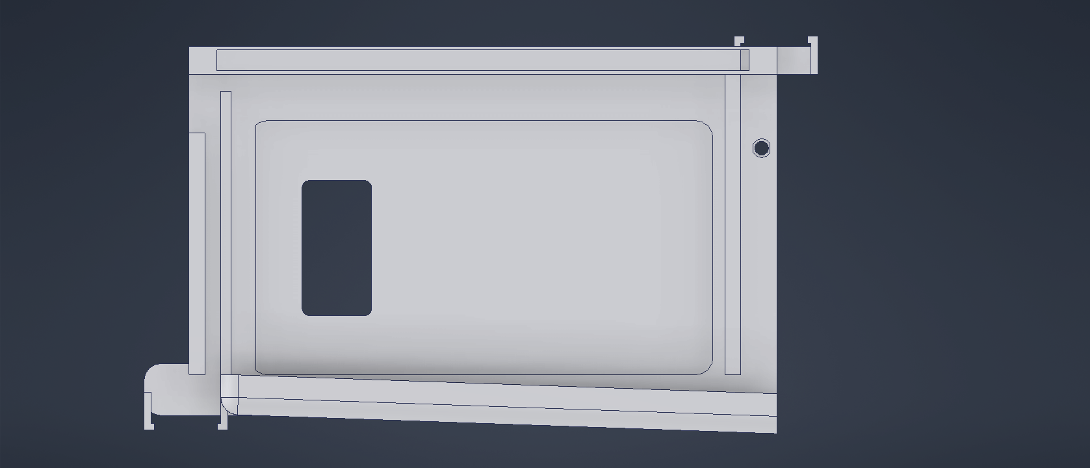
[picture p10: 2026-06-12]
hardware/CAD/images/panel-suport.png

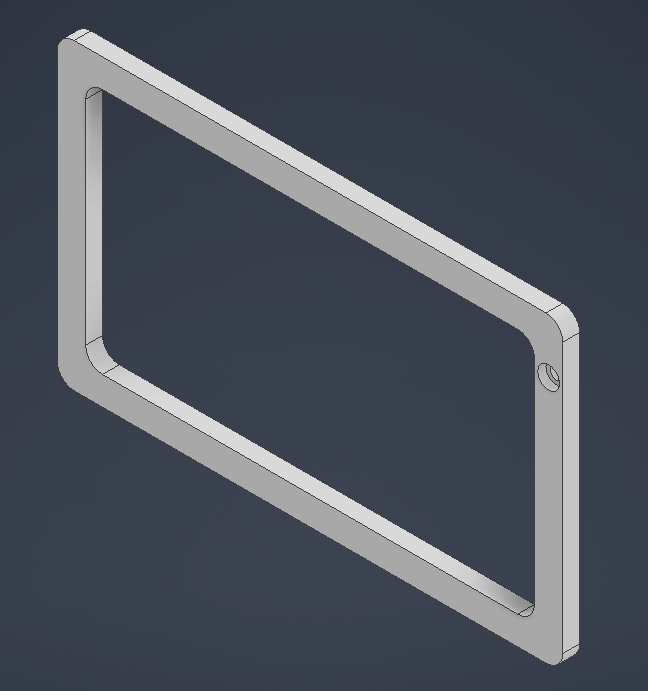
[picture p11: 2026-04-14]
hardware/CAD/images/Frame.png

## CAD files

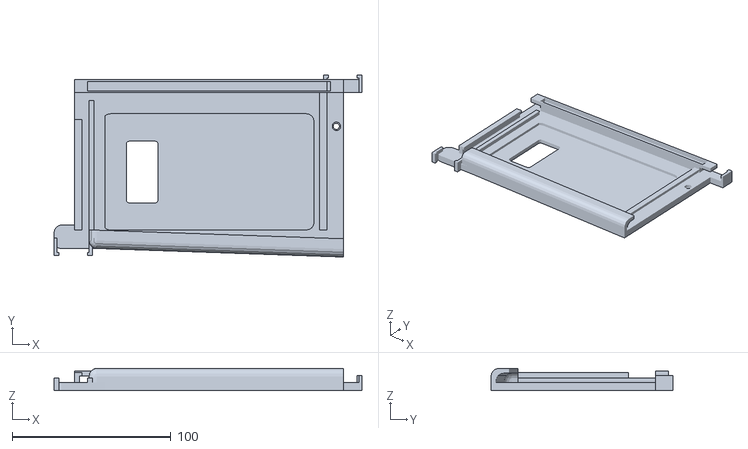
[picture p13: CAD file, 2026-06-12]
hardware/CAD/stl/panel-suport.stl
193.8 x 114.6 x 14.0

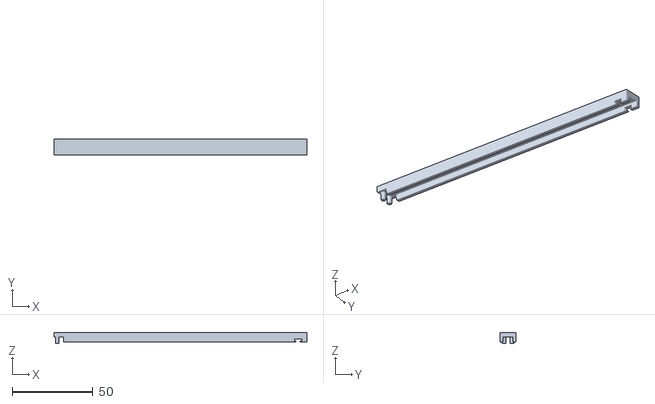
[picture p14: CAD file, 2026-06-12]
hardware/CAD/stl/Wiper-support.stl
156.4 x 10.0 x 7.00

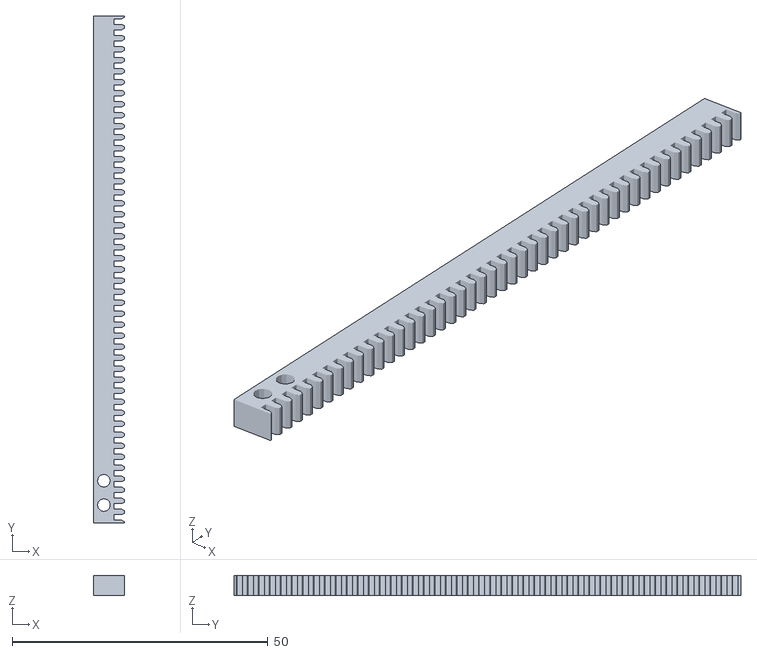
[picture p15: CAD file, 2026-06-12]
hardware/CAD/stl/Gear-Rack.stl
6.00 x 99.0 x 4.00

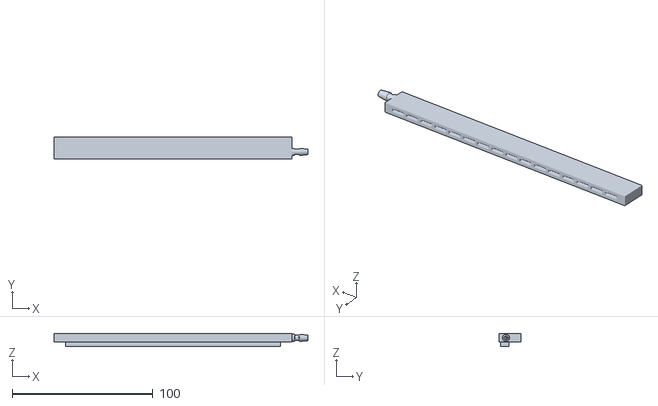
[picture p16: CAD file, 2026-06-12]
hardware/CAD/stl/Sprinkler.stl
180.5 x 15.5 x 9.00

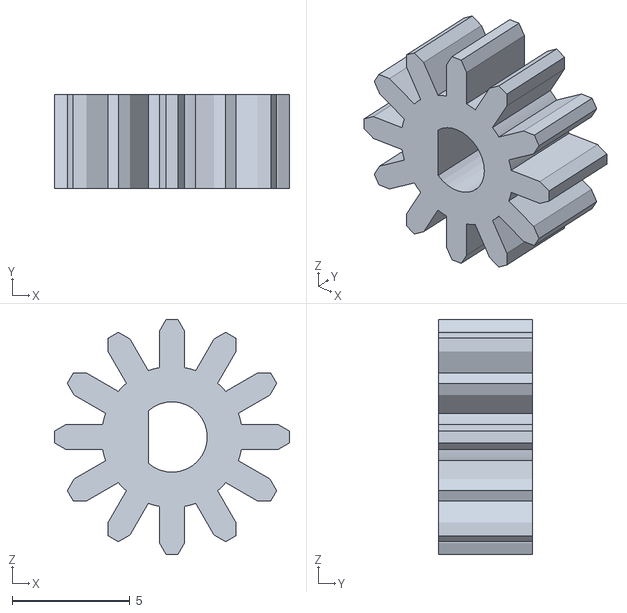
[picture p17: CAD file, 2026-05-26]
hardware/CAD/stl/Gear.stl
10.0 x 4.00 x 10.0

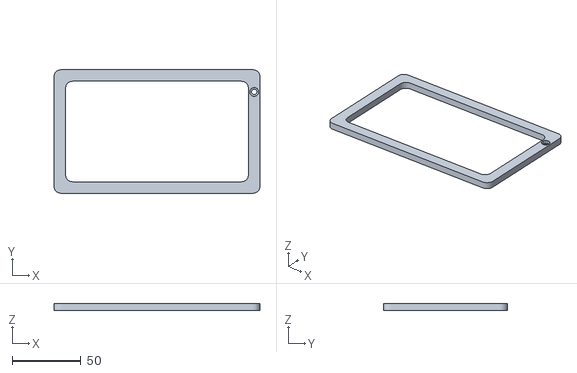
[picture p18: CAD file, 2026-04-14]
hardware/CAD/stl/Frame.stl
150.0 x 90.0 x 5.00

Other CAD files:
hardware/CAD/iam/assembly.iam
hardware/CAD/ipn/assembly.ipn
hardware/CAD/ipt/Frame.ipt
hardware/CAD/ipt/Gear-Rack.ipt
hardware/CAD/ipt/Gear.ipt
hardware/CAD/ipt/Sprinkler.ipt
hardware/CAD/ipt/Wiper-support.ipt
hardware/CAD/ipt/panel-suport.ipt

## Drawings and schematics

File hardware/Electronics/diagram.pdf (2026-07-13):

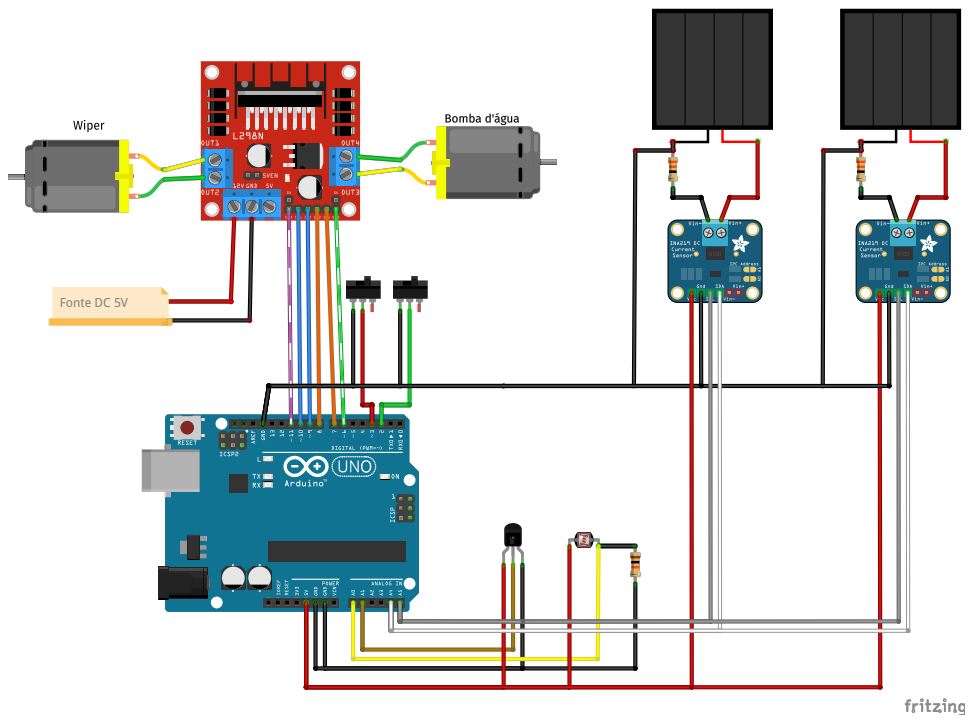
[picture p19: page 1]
Fonte DC 5V

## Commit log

2026-04-07 chore: adiciona readme.md para melhor esclarecimento do projeto
2026-04-07 feat: Apresentacao da proposta de projeto
2026-04-08 add: panel suport
    [panel-suport.ipt]
2026-04-08 test: implementa testes unitários, linting (ruff) e checagem de tipos (pyright)
2026-04-08 ci: implementa workflow do GitHub Actions para testes e linting com uv
2026-04-08 fix: adiciona monitoramento e comando para fim de curso inicial (HOME)
2026-04-08 feat: implementa sistema de logging em CSV para telemetria e eventos
2026-04-08 chore: adiciona Makefile para simplificar comandos do dashboard
2026-04-14 add: adicao da calha de escoamento
    [Frame.ipt, Frame.stl, panel-suport.0004.ipt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]
2026-04-14 add: print das partes
2026-04-14 fix: remove ignored files
    [panel-suport.0004.ipt]
2026-04-22 chore: adiciona aviso de documentos legados de apresentacao
2026-04-22 feat: Adiciona descritivo do hardware eletronico
    [Diagram.fz]
2026-04-22 fix: ajuste de conexoes do LDR
    [Diagram.fz]
2026-04-22 fix: ajuste do fillet da calha
    [panel-suport.ipt, panel-suport.stl]
2026-04-22 add: criacao da engrenagem de acoplamento com motor
    [Gear.ipt, Gear.stl]
2026-04-22 style: organizacao das pastas
    [Frame.ipt, Frame.stl, Gear.ipt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]
2026-04-22 fix: dimensoes ajustadas do ldr
    [panel-suport.ipt, panel-suport.stl]
2026-04-22 feat: melhora servico de clima e configura o Campus como local padrao
2026-05-20 chore: alteracao da engrenagem
    [Gear.ipt, Gear.stl]
2026-05-26 feat: sensor ina219 funcionou e comecando dashboard
    [events_history.csv, telemetry_history.csv]
2026-05-26 refactor: corrige erros de lint (Ruff) e corrige teste unitário do controle de bomba
2026-05-26 criacao do rack de contato para engrenagem
    [Gear-Rack.ipt, Gear-Rack.stl]
2026-05-26 Furacao para acoplar o wiper
    [Gear-Rack.ipt, Gear-Rack.stl]
2026-05-26 fix: controle de concorrência na limpeza, parada automática da bomba e chamadas climáticas não-bloqueantes
2026-06-03 fix: ajuste do diagrama eletrico
    [Diagram.fz]
2026-06-10 feat: adição das novas peças
    [Sprinkler.ipt, Sprinkler.stl, Wiper-support.ipt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]
2026-06-30 fix: diagrama eletrico ajustado
    [diagram.fz]
2026-07-01 doc: atualiza artigo do conict com novo fluxograma, diagrama e metodologia de ensaios
2026-07-05 docs(article): organiza imagens em diretorio compartilhado, remove renders nao utilizados do Frame
    Aponta o CONICT/preambulo.tex para o docs/Article/images/ compartilhado
    via graphicspath, em vez de manter copias identicas de cada figura
    dentro de CONICT/. Remove tambem frame_cad.png/wiper_cad.png/
    cremalheira_cad.png, que mostravam uma peca solta e nao montada e
    foram substituidas pela figura de vista explodida.
2026-07-05 hardware(cad): adiciona assembly e apresentacao de vista explodida
    Introduz o assembly.iam, combinando Gear-Rack, Gear, Wiper-support,
    Sprinkler e panel-suport (Frame excluido intencionalmente, pois nao
    faz mais parte do design), alem do assembly.ipn (Presentation do
    Inventor com os componentes deslocados/explodidos) e seu render
    isometrico exportado, assembly.png.
    [assembly.iam, assembly.ipn]
2026-07-05 docs(article): adiciona vista explodida da montagem no lugar do frame
    Substitui as figuras soltas de CAD (frame_cad, wiper_cad, cremalheira_cad)
    por uma unica figura de vista explodida da montagem mecanica (sem o
    Frame, que nao e mais utilizado), com legenda numerada dos 5
    componentes: Cremalheira, Pinhao, Suporte do Rodo, Sprinkler e Suporte
    dos Paineis. Inclui fallback via IfFileExists para o main.tex/artigo.tex
    continuarem compilando caso a imagem nao esteja presente.
    Tambem corrige, no artigo.md, os links absolutos quebrados para o Guia
    de Hardware Eletronico e para hardware.py/main.py/app.py, ja que essas
    linhas ficavam adjacentes as removidas na mesma edicao.
2026-07-05 docs(article): unifica bibliografia entre CONICT e artigo.tex
    Adiciona ao bibliografia.bib compartilhado (docs/Article/CONICT/) as
    entradas electronics_guide e telemetrix_ref, ate entao exclusivas do
    artigo.tex. Troca o thebibliography manual do artigo.tex por
    bibliographystyle{plain} + bibliography{CONICT/bibliografia}, eliminando
    a lista de referencias duplicada. Remove docs/Article/referencias.bib,
    que ficou totalmente redundante.
2026-07-05 docs(article): esclarece relacao entre ensaio curto e ensaio de campo
    Adiciona uma frase de transicao no CONICT/main.tex, no artigo.tex e no
    artigo.md deixando explicito que o ensaio curto em ambiente controlado
    com luz artificial (validacao preliminar) e o ensaio de campo de 30 dias
    com sujeira natural (validacao definitiva) sao estagios complementares
    e distintos, evitando a impressao de inconsistencia entre as duas
    versoes do artigo.
2026-07-05 docs(article): recompila PDFs do CONICT e do artigo longo
    Atualiza main.pdf/main.aux/main.log (CONICT) e artigo.pdf apos as
    mudancas de vista explodida, bibliografia unificada e nota de
    metodologia. CONICT permanece com 6 paginas; artigo.tex com 11.
2026-07-05 docs(article): corrige edicao/ano do CONICT no cabecalho e remove arquivos orfaos
    O cabecalho ainda citava "16º ... 2025", desatualizado em relacao ao
    rodape e ao comentario de topo do main.tex, que ja referenciam o
    17º CONICT 2026 (confirmado no site oficial do IFSP). Tambem remove
    grafico_1.png, grafico_2.png e logo_ifsp.png, sobras do template que
    nao sao referenciadas em nenhum .tex.
2026-07-05 docs(article): recompila PDFs com imagem indexada e corrige bibtex ausente no Makefile
    O Makefile de build (CONICT e artigo) declarava a variavel BIBTEX mas
    nunca a chamava, entao as citacoes ficavam undefined e o .bbl nunca
    era gerado de fato pelo `make`. Adiciona o passo de bibtex entre as
    passadas do pdflatex.
    Tambem aumenta a figura da vista explodida (8cm -> 11cm no CONICT,
    0.7 -> 0.9 textwidth no artigo) e recompila ambos os PDFs para
    embutir a versao da imagem com os balareos numerados (1-5) que a
    legenda ja descrevia. main.pdf do CONICT permanece com 6 paginas,
    dentro do limite da chamada.
2026-07-06 docs(article): adiciona monografia detalhada com dashboard e endpoints
    Cria documento estilo monografia (docs/Article/monografia.tex) expandindo
    o artigo com referencial teorico, tabelas de BOM/pinout/endpoints REST,
    screenshot real do dashboard Streamlit e discussao de custos/limitacoes.
2026-07-07 docs: atualiza modelo do artigo para CONICT 2026
2026-07-07 docs: adiciona documento sem nome para submissao
2026-10-07 docs(conict): atende correções do avaliador para a versão final
    - Introdução: substitui o dado de "mais de um terço" (mês recorde, Ember)
    pela série anual do BEN/EPE (eólica+solar 20,7% -> 26,4%, 2023-2025)
    - Figura 1: gráfico anual vetorial (pgfplots) com destaque para a solar;
    figuras ampliadas para legibilidade na versão impressa
    - Discute a falta de comparabilidade entre as perdas da Ásia e da
    América do Sul e os fatores que explicam a diferença
    - Discute a variação intradiária da perda no gráfico de soiling
    - Adiciona estimativa da energia por ciclo de limpeza e do ganho
    energético líquido (nova equação e etapa no procedimento de ensaio)
    - Corrige o nome da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
2026-11-06 feat(dashboard): atualizacao automatica, historico real e estado dos atuadores
    Reaplica o trabalho do PR #9, que foi fechado sem merge e teve o branch
    removido, portanto nunca chegou a main.
    - hardware.py: set_pump/move_wiper/stop_wiper passam a refletir o estado
    em hw.state. O automation_loop (vindo do PR #10, ja na main) ja lia
    hw_data["pump"] para desligar o arrefecimento, mas esse campo nunca era
    escrito e ficava sempre "off", impedindo o desligamento automatico.
    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
2026-11-06 ci: fixa o Python em 3.13 para destravar o build de dependencias
    O CI esta vermelho na main desde 13/10 (run #39). A etapa "Install
    dependencies" falha e ruff, pyright e pytest nem chegam a rodar, entao
    nenhum PR consegue ficar verde.
    Causa: "uv python install" sem versao instala o CPython mais recente
    disponivel, hoje o 3.15.0b4, que e um pre-release. Como ainda nao existem
    wheels para 3.15, o uv tenta compilar tudo da fonte e quebra na primeira
    extensao nativa (no CI, rpds-py com PyO3 0.27.2, que suporta no maximo o
    3.14; localmente a mesma falha aparece no pyarrow via cmake).
    Correcao: adiciona firmware/dashboard/.python-version fixado em 3.13 e faz
    a etapa "Set up Python" entrar no dir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

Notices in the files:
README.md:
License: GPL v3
